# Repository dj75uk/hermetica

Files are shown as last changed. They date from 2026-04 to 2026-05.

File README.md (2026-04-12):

# Project Hermetica

## Overview
**Project Hermetica** is a modular, scalable **flight control unit (FCU) platform** designed for unmanned aerial systems ranging from hobby-grade builds to industrial and commercial UAVs.

It is built from the ground up to prioritise **reliability, observability, and architectural correctness**, avoiding the typical “black box” approach seen in many existing flight controllers.

## Purpose
Hermetica exists to solve a fundamental problem in UAV systems:

> Flight controllers are often opaque and difficult to validate, when they should be transparent, deterministic, and testable.

The platform aims to:
- Provide a **robust and distributed deterministic flight control stack**
- Enable **deep system introspection** for debugging and validation
- Support **modern communication architectures** (notably CAN-based systems)
- Serve as a foundation for **autonomous and safety-critical UAV applications**

## Design Philosophy
Hermetica is built on a set of strict engineering principles:

- **Modularity by design**  
  Components must be composable, replaceable, and independently testable  

- **Deterministic behaviour**  
  Timing, control loops, and data paths must be predictable and measurable  

- **Observability first**  
  Internal system state must be visible, logged, and analysable  

- **Fail explicitly, not silently**  
  Fault detection and handling are first-class concerns  

- **Architecture over convenience**  
  Clean design is prioritised over short-term integration hacks  

## System Architecture
Hermetica is structured as a **distributed flight control system**:

- **Power Management**
  
  Power supply, control, regulation, protection and monitoring.
  
- **Distibuted Core FCU**  
  High-performance MCU(s) responsible for control loops, sensor fusion, and coordination  

- **Peripheral Modules**  
  Sensors, actuators, and payload interfaces connected via defined interfaces  

- **Communication Backbone**  
  FDCAN-based architecture for robust, fault-tolerant communication  

- **Telemetry & Diagnostics Layer**  
  High-rate, structured data output for monitoring and analysis  

## Core Capabilities
- Multi-mode flight control (manual, stabilised, autonomous)  
- Sensor fusion (IMU, GNSS, barometer, magnetometer, optional optical flow)  
- High-frequency, deterministic control loops  
- Integrated health monitoring and fault detection  
- Comprehensive logging and telemetry streaming  
- Support for multiple protocols (CAN, UART, SBUS/FBUS, MAVLink)  

## Hardware Approach
Hermetica hardware is designed to be:
- **Electrically robust** (ESD protection, signal integrity, stable power delivery)  
- **Expandable** with clearly defined interfaces  
- **Integration-aware** without hardcoding external constraints  
- **Unconstrained by legacy layouts**  

## Software Approach
- Bare-metal or RTOS-based execution  
- Clear separation of:
  - Real-time control paths  
  - Communication layers  
  - Diagnostics and logging  
- Designed for **testability** (HIL/SIL, fault injection)  
- Secure update and configuration mechanisms  

## Relationship to Aetherion
Hermetica is developed alongside [**Project Aetherion**](https://github.com/dj75uk/aetherion), which serves as its **real-world validation platform**.

- Hermetica defines the control system  
- Aetherion validates it under real conditions  

This separation keeps Hermetica architecturally clean while ensuring it meets real-world constraints.

## Key Differentiators
- **CAN-first architecture** instead of UART-centric designs  
- **Proper FBUS support** for high-performance peripherals  
- **Deep observability and diagnostics**, not just basic telemetry  
- **Scalable design** from hobby to industrial applications  
- **Explicit fault handling**, not optimistic assumptions  

## Target Use Cases
- Advanced hobbyist UAV platforms  
- Research and academic systems  
- Industrial UAV development  
- Autonomous flight systems  

## Long-Term Vision
Hermetica is intended to evolve into:
- A fully autonomous flight control platform  
- A modular ecosystem with open interface specifications  
- A reference architecture for next-generation UAV systems  

Future directions include:
- Distributed flight control across multiple nodes  
- AI-assisted navigation and control  
- Swarm coordination  
- Pathways toward safety-critical certification

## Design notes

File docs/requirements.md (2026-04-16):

# Project Hermetica – System Requirements Specification

**Version:** 0.1  
**Date:** 2026-04-16  
**Owner:** Daniel Johnson  
**Status:** Draft  

---

## 1. Scope

This document defines the high-level system requirements for Project Hermetica.

These requirements describe what the system must achieve independent of specific implementation details.

---

## 2. Functional Requirements

### Flight Control

**FR-001 [MVP]**  
The system shall provide closed-loop stabilised flight control for fixed-wing UAV platforms.

**FR-002 [MVP]**  
The system shall support manual flight control input from at least one external RC receiver.

**FR-002 [MVP]**  
The system shall support aileron control surfaces.

**FR-002 [MVP]**  
The system shall support rudder control surfaces.

**FR-002 [MVP]**  
The system shall support elevator control surfaces.

**FR-002 [MVP]**  
The system shall support ruddervator control surfaces.

**FR-002 [FUTURE]**  
The system shall support elevon control surfaces.

**FR-002 [MVP]**  
The system shall support flap control surfaces.

**FR-002 [FUTURE]**  
The system shall support flapperon control surfaces.

**FR-002 [FUTURE]**  
The system shall support canard control surfaces.

**FR-003 [MVP]**
The system shall support at least 4 independant engines.

**FR-003 [MVP]**
The system shall support independant thrust curves for each engine.

**FR-004 [MVP]**
The system shall support multiple airframe configurations.

**FR-004 [MVP]**
The system shall support differential thrust.
- Source: DC-010, DC-025 

**FR-007 [MVP]**  
The system shall support multiple flight modes.

**FR-008 [FUTURE]**  
The system shall support autonomous mission execution.

**FR-009 [MVP]**  
The system shall generate independent control outputs for at least:
- throttle
- pitch
- roll
- yaw
- flaps

---

### Sensor Processing

**FR-012 [MVP]**  
The system shall acquire inertial measurement data from onboard sensors.

**FR-013 [MVP]**  
The system shall support fusion of:
- gyroscope
- accelerometer
- magnetometer

**FR-014 [FUTURE]**  
The system shall support optional integration of:
- GNSS
- barometric pressure
- pitot airspeed
- range sensors

---

### Distributed Architecture

**FR-015 [MVP]**  
The system shall support distributed processing across multiple nodes.

**FR-016 [MVP]**  
The system shall allow independent functional modules to be added without modification of the core flight controller.

**FR-017 [MVP]**  
The system shall support a minimum of 24 connected nodes.

---

## 3. Performance Requirements

**PR-001 [MVP]**  
The primary flight control loop shall operate at 1000 Hz with cycle-to-cycle jitter not exceeding 50 µs.

**PR-002 [MVP]**  
The system shall produce actuator command outputs at a minimum frequency of 500 Hz.

**PR-003 [MVP]**  
The system shall have and end-to-end control latency not exceeding 20 ms.

**PR-004 [MVP]**  
The system shall complete cold boot within 3 seconds.

**PR-005 [FUTURE]**  
The system shall scale to at least 24 networked nodes without loss of deterministic communication.

---

## 4. Safety Requirements

**SR-001 [MVP]**  
The system shall prevent actuator arming while debugging hardware is connected.

**SR-002 [MVP]**  
The system shall detect loss of critical sensor data.

**SR-003 [MVP]**  
The system shall detect loss of communication with critical nodes.

**SR-004 [MVP]**  
The system shall transition to a defined failsafe state upon loss of pilot control input.

**SR-005 [MVP]**  
The system shall reject commands that exceed defined airframe safety limits.

**SR-006 [MVP]**  
The system shall tolerate failure of non-critical nodes without loss of flight control.

---

## 5. Interface Requirements

### Internal Communication

**IR-001 [MVP]**  
The system shall support deterministic communication
between distributed nodes.

**IR-002 [MVP]**  
All stack layers shall communicate over a shared internal backbone.

**IR-003 [MVP]**  
The system shall support deterministic time-synchronised communication between nodes.

---

### External Interfaces

**IR-004 [MVP]**  
The system shall support at least one RC receiver interface.

**IR-005 [MVP]**  
The system shall provide a standardised debug interface on each stack layer.

**IR-006 [FUTURE]**  
The system shall support a ground telemetry interface.

---

## 6. Electrical Requirements

**ELR-001 [MVP]**  
The system shall operate from a dual redundant battery input.

**ELR-002 [MVP]**  
The system shall support an input voltage range of at least 2S to 8S LiPo equivalent.

**ELR-003 [MVP]**  
The system shall provide isolated power domains for:
- flight stack
- external nodes

**ELR-004 [MVP]**  
The system shall monitor:
- voltage
- current
- temperature
- power consumption

---

## 7. Mechanical Requirements

**MR-001 [MVP]**  
The system shall support a vertically stacked PCB architecture.

**MR-002 [MVP]**  
Individual stack layers shall be replaceable without redesign of adjacent layers.

**MR-003 [MVP]**  
External nodes shall connect using defined standard interfaces.

---

## 8. Environmental Requirements

**ENV-001 [MVP]**  
The system shall operate at temperatures between -20°C and +70°C minimum.

**ENV-002 [MVP]**  
The system shall tolerate vibration consistent with fixed-wing UAV operation.

**ENV-003 [FUTURE]**  
The system shall tolerate temporary electrical transients without system reset.

---

## 9. Maintainability Requirements

**MT-001 [MVP]**  
The system shall support firmware updates through a standardised service interface.

**MT-002 [MVP]**  
Each node shall support independent firmware programming.

**MT-003 [FUTURE]**  
The system shall support remote firmware updates.

---

## 10. Verification Requirements

**VR-001**  
Each requirement in this document shall be verifiable by one or more of:
- inspection
- analysis
- test
- demonstration

**VR-002**  
Each implemented subsystem shall trace back to one or more requirements defined in this document.

---

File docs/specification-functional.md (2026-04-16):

# Project Hermetica – System Specification

**Version:** 0.6  
**Date:** 2026-04-15  
**Owner:** Daniel Johnson  
**Status:** Draft  

---

## Nomenclature

### On the name "Hermetica"

### On the name "Aetherion"

### Definitions

#### FCU
The FCU is the Hermetica hardware and software combined together to form a working, cohesive system. It encompasses the centralised control system and any communicating devices.

#### Flight Control Stack
A centralised physical structure comprised of vertically stacked PCBs with a common Backbone, responsible for primary flight-critical functions.

#### Backbone
A vertically stacking header facilitating power distribution and signalling between Stack Layers.

#### Stack Layer
A physical PCB within the Flight Control Stack.

#### Node
A physical PCB external to the Flight Control Stack, connected via defined interfaces and operating semi-independently.

#### Role
A logical grouping of Responsibilities, independent of physical implementation.

#### Authority
The level of control a Role has over system behaviour and decision making.

#### Responsibility
A defined aspect of system behaviour that a Role is accountable for.

#### Power Domain
A distinct electrical rail with defined characteristics and purpose.

#### System State
The current operational state of the FCU and all information pertaining to it.

---

## Units

Wherever possible, SI units (and derived units) will be used across the system.

| Value | Unit | Symbol | Examples |
|---|---|---|---|
| Time | Seconds | s | |
| Attitute | degrees | ° | Roll, Pitch, Yaw |
| Attitute Rates | degrees per second | °s<sup>-1</sup> | Roll-Rate, Pitch-Rate, Yaw-Rate |
| Heading|degrees|°| Magnetic Heading, True Heading |
| Scalar speed |metres per second | ms<sup>-1</sup> | Airspeed, Groundspeed, VSI |
| Altitude | metres | m | Barometric altitude, GPS altitude, IMU altitude, Ranged altitude |
| Current | Amps  | A | Primary bus current |
| Voltage | Volts | V | Primary bus voltage |
| Power | Watts | W | Primary bus power |
|Frequency|Hertz|Hz| Main loop cycle frequency |
|Temperature|Celcius|°C| Outside air temperature, cabin temperature |
|Pressure|Pascals|Pa| Barometric pressure, Pitot pressure |
|Distance|metres|m| Total flight distance, distance to home |

---

## Purpose

Hermetica is a **modular, distributed, resiliant, scalable flight control unit (FCU) platform** designed to support UAV systems ranging from hobbyist to industrial-grade deployments.

The system is intended to:
- Provide **deterministic real-time flight control**
- Enable a **modular ecosystem**
- Establish a **CAN-FD-first architecture**
- Support progression toward **full autonomy**

---

## System Architecture

### Architectural Model

Hermetica follows a **hybrid architecture**:
- A **scalable, centralised Flight Control Stack** for flight-critical functions
- **Distributed Nodes** for extensibility and scalability

### Core Components

- Flight Control Stack
- External Nodes
- Sensor Systems
- Actuation Systems
- CAN-FD Backbone
- Ground Interface

### Design Principles

- **Strict role separation**
- **Decoupled integration** (no hard dependency on specific airframe)
- **Deterministic real-time behavior**
- **Fail-operational where possible**
- **Hardware/software modularity**
- **Open interface specifications**

---

## Logical System Model

### [CAN-FD Message Model](message-model.md)

### System State

The System State is effectively a normalised view of the current operating conditions of the FCU and the airframe.

| Variable | Data Type | Notes |
|---|---|---|
| Bench Mode | BOOL | |
| Launched | BOOL | |
| Armed | BOOL | |
| Current Flight Mode | ENUM | |
| Current Throttle Rate | FLOAT | |
| Current Pitch Rate | FLOAT | |
| Current Roll Rate | FLOAT | | 
| Current Yaw Rate | FLOAT | | 
| Current Throttle | FLOAT | |
| Current Pitch | FLOAT | |
| Current Roll | FLOAT | | 
| Current Yaw | FLOAT | | 
| Current Flaps | FLOAT | | 
| Current VSI | FLOAT | | 
| Current Barometric Pressure | FLOAT | | 
| Current Pitot Pressure | FLOAT | | 
| Current Barometric Altitude | FLOAT | | 
| Current GPS Altitude | FLOAT | | 
| Current Ranged Altitude | FLOAT | | 

| Variable | Data Type | Notes |
|---|---|---|
| Input Throttle | FLOAT | |
| Input Pitch | FLOAT | |
| Input Roll | FLOAT | | 
| Input Yaw | FLOAT | | 
| Input Flaps | FLOAT | | 
| Input Differential Throttle | FLOAT | Left/Right Throttle bias for twin-engines | 
| Input Flight Mode | ENUM | | 

| Variable | Data Type | Notes |
|---|---|---|
| Output Throttle | FLOAT | |
| Output Pitch | FLOAT | |
| Output Roll | FLOAT | | 
| Output Yaw | FLOAT | | 
| Output Flaps | FLOAT | | 
| Output Differential Throttle | FLOAT | | 

### Roles

A Role:
- Owns a clearly defined functional domain
- Has explicitly defined inputs and outputs
- May enforce local constraints within its domain
- May participate in system-wide decision making depending on its authority

The FCU is composed of a set of defined Roles. Each Role encapsulates a specific set of Responsibilities and operates within a defined domain.

Roles are independent of physical implementation and may be assigned to any suitable Stack Layer or Node.

---

#### Flight Control Role

The Flight Control Role is responsible for generating actuator commands required to achieve and maintain controlled flight.

Responsibilities:
- Stabilisation (rate and attitude control)
- Navigation (position and velocity control)
- Flight mode handling and transitions
- Command generation for actuators
- Enforcement of flight-related constraints

Inputs:
- Sensor data (IMU, GNSS, barometer, etc.)
- Pilot commands (via RC or ground interface)
- System State
- Constraints from higher-authority roles

Outputs:
- Actuator command signals
- Flight state information

---

#### Sensor Processing Role

The Sensor Processing Role is responsible for acquiring, validating, and conditioning sensor data for use by other Roles.

Responsibilities:
- Sensor data acquisition
- Calibration and compensation
- Data validation and plausibility checking
- Sensor fusion (if implemented within this role)

Inputs:
- Raw sensor measurements

Outputs:
- Conditioned sensor data
- State estimates (if applicable)
- Sensor health/status information

---

#### Actuation Role

The Actuation Role is responsible for converting actuator commands into physical outputs.

Responsibilities:
- Driving ESCs and servos
- Output signal generation (PWM, digital protocols, etc.)
- Monitoring actuator response (if feedback is available)
- Enforcing actuator-level safety constraints

Inputs:
- Actuator commands from Flight Control Role
- System State
- Constraints from higher-authority roles

Outputs:
- Physical actuator signals
- Actuator status and health information

---

#### Power Management Role

The Power Management Role is responsible for the distribution, monitoring, and protection of electrical power within the FCU.

Responsibilities:
- Power distribution across defined Power Domains
- Voltage, current, and temperature monitoring
- Fault detection and protection
- Power domain control (enable/disable)
- Enforcement of electrical safety constraints

Inputs:
- Electrical measurements (voltage, current, temperature)
- System State

Outputs:
- Power status information
- Fault signals
- Power domain control signals

---

#### Communication Role

The Communication Role is responsible for the exchange of data between system components and external interfaces.

Responsibilities:
- Message transport across internal and external interfaces
- Protocol handling and abstraction
- Routing of messages between Roles
- Ensuring data integrity and timing constraints

Inputs:
- Messages from Roles and external interfaces

Outputs:
- Routed and transmitted messages
- Communication status information

---

#### System Management Role

The System Management Role is responsible for overall system coordination and state management.

Responsibilities:
- System State management and transitions
- Arming and disarming logic
- Coordination between Roles
- Enforcement of system-level constraints
- Handling of global fault conditions

Inputs:
- Status and health information from all Roles
- External control inputs

Outputs:
- System State
- Control signals affecting other Roles
- Global fault responses

---

#### Payload Role

The Payload Role is responsible for control and management of mission-specific payloads.

Responsibilities:
- Payload control and operation
- Data acquisition from payload systems
- Integration with mission objectives

Inputs:
- Commands from Flight Control or external interfaces

Outputs:
- Payload data
- Payload status information

---

### Responsibilities

Responsibilities define behavioural obligations of Roles.

#### Assignment

- Every Responsibility shall be owned by exactly one Role.  
- A Role may own multiple Responsibilities.  
- Responsibilities shall not be shared between Roles to avoid ambiguity in ownership.  

---

#### Scope

- Each Responsibility shall have clearly defined boundaries.  
- Responsibilities shall not overlap in scope.  
- Responsibilities may depend on outputs from other Responsibilities but shall not duplicate them.  

---

#### Inputs and Outputs

- Each Responsibility shall define its required inputs.  
- Each Responsibility shall define its expected outputs.  
- Inputs and outputs shall be explicitly defined to enable consistent integration between Roles.  

---

#### Behavioural Guarantees

- Each Responsibility shall define the conditions it must maintain or enforce.  
- Responsibilities shall produce deterministic outcomes given valid inputs.  
- Responsibilities shall handle invalid or missing inputs in a defined manner.  

---

#### Constraints

- Responsibilities may enforce constraints within their domain.  
- Responsibilities shall operate within constraints imposed by higher-authority Roles.  
- Conflicting constraints shall be resolved according to the Authority model.  

---

#### Failure Handling

- Each Responsibility shall define failure conditions relevant to its domain.  
- Responsibilities shall detect and report failures where possible.  
- Responsibilities shall define safe behaviour in the presence of faults.  

---

#### Independence

- Responsibilities shall be independent of physical implementation.  
- Responsibilities shall not assume specific hardware, communication interfaces, or execution environments.  

---

#### Composability

- Responsibilities shall be designed to allow composition into larger system behaviours.  
- Responsibilities may be reused across different Roles or system configurations, provided ownership remains unambiguous.  

---

### Authority Model

- Higher-authority Roles define intent and constraints
- Lower-authority Roles execute within constraints
- Lower layers may reject unsafe commands
- System Management Role arbitrates conflicts
- Power Management Role has ultimate override in electrical faults

---

### Hierarchical Control Architecture

The FCU implements a hierarchical control architecture where high-level intent is progressively transformed into physical actuation.

---

#### Strategic Level (may be omitted)
- Defines long-term objectives (map this entire area)

#### Tactical Level
- Defines short-term objectives (waypoints, timing)

#### Execution Level
- Generates paths and vectors

#### Flight Dynamics Level
- Converts paths into attitude/altitude targets

#### Flight Control Level
- Stabilises via control loops

#### Actuation Level
- Drives physical outputs

---

## Functional Capabilities

### Flight Control

- Stabilisation
- Navigation
- Mission execution

(Control strategy TBD)

---

### Flight Modes

- **Disabled / Fully Manual Control**  
Direct RC receiver pass-through with no protection from pilot error

#### Building Blocks

- **Controlled Throttle**  
Throttle is directly proportional to pilot input within configurable safety margins
- **Controlled Pitch-Rate**  
Pitch-rate is directly proportional to pilot input within configurable safety margins
- **Controlled Pitch**  
Pitch is directly proportional to pilot input within configurable safety margins
- **Controlled Roll-Rate**  
Roll-rate is directly proportional to pilot input within configurable safety margins
- **Controlled Roll**  
Roll is directly proportional to pilot input within configurable safety margins
- **Controlled Yaw-Rate**  
Yaw-rate is directly proportional to pilot input within configurable safety margins

- **Auto Pitch-Rate**  
Pitch is controlled by the FCU, any pilot input disables **Auto Pitch-Rate** and enables **Controlled Pitch-Rate**

- **Auto Pitch**  
Pitch is controlled by the FCU, any pilot input disables **Auto Pitch** and enables **Controlled Pitch**

- **Auto Roll-Rate**  
Pitch is controlled by the FCU, any pilot input disables **Auto Roll-Rate** and enables **Controlled Roll-Rate**

- **Auto Roll**  
Pitch is controlled by the FCU, any pilot input disables **Auto Roll** and enables **Controlled Roll**

- **Altitude Hold**

- **Airspeed Hold**
  - Enables **Controlled Throttle**

#### Basic Flight Modes

- **Semi-Manual**  
Limited RC receiver pass-through with configurable airframe and flight-envelope protection
- **Stabilised**  
IMU assisted flight, airframe will maintain whatever *attitude-rates* the pilot commands
  - Enables **Controlled Throttle**
  - Enables **Controlled Pitch-Rate**
  - Enables **Controlled Roll-Rate**
  - Enables **Controlled Yaw-Rate**
- **Autolevel**  
IMU assisted flight, airframe will maintain whatever *attitude* the pilot commands until the command is ceased, then the airframe will self-level pitch and roll
  - Pilot throttle input controls throttle directly
  - Pilot yaw input controls rudder directly
  - Pilot pitch input controls final pitch angle
  - Pilot roll input controls final roll angle

- **Launch** *TODO: This seems unsafe, review*    
Aircraft will maintain a preset throttle and pitch angle until the mode is disengaged
  - Pilot throttle input controls are disabled, the aircraft maintains the configured launch throttle
  - Pilot yaw input controls are disabled, the aircraft maintains the yaw angle of launch
  - Pilot pitch input controls are disabled, the aircraft maintains the configured launch pitch
  - Pilot roll input controls are disabled, the aircraft maintains a roll angle of zero  

- **Loiter**  
Aircraft will fly in a circle around the location the aircraft is at when the mode is enabled, maintaining a fixed altitude. If no GPS/GNSS is available then the aircraft will use the IMU to maintain a constant yaw rate while maintaining a fixed altitude.

#### Advanced Flight Modes

- **Return To Home (RTH)**  
Aircraft will return to the point the flight started then enter **Loiter** mode at that point

- **Failsafe**
- **Autonomous**

---

| Mode | Throttle  |  Yaw | Pitch | Roll | Flaps |
|---|---|---|---|---|---|
| Full-Manual | Direct | Direct | Direct | Direct | Direct |
| Semi-Manual | Limited | Limited | Limited | Limited | Limited |
| Stabilised  |-----------|------|-------|------|-------|
| Autolevel |-----------|------|-------|------|-------|
| Loiter |-----------|------|-------|------|-------|
| RTH |-----------|------|-------|------|-------|
| Launch |-----------|------|-------|------|-------|
| Full-manual |-----------|------|-------|------|-------|
| Full-manual |-----------|------|-------|------|-------|
| Full-manual |-----------|------|-------|------|-------|
| Full-manual |-----------|------|-------|------|-------|
| Full-manual |-----------|------|-------|------|-------|
| Full-manual |-----------|------|-------|------|-------|
| Full-manual |-----------|------|-------|------|-------|
| Full-manual |-----------|------|-------|------|-------|
| Full-manual |-----------|------|-------|------|-------|
| Full-manual |-----------|------|-------|------|-------|

---

### Sensor Handling

- IMU, GNSS, Barometer, Magnetometer
- Optional sensors

Sensor fusion TBD

---

### Communication

#### Flight Stack Backbone:

The Backbone must provide both power, data about the power and communications and signalling. 

**Power:**

| Name | Notes |
|---|---|
| 5V<sub>STACK</sub> | Power bus for the Flight Stack |
| 5V<sub>NODES</sub> | Power bus for the Nodes | 
| GND<sub>POWER</sub> | Power ground |
| GND<sub>SIGNAL</sub>  | Signal ground |

**Communications & Signalling:**

| Name | Data type | Description |
|---|---|---|
| PG<sub>STACK</sub> | BOOL | 5V<sub>STACK</sub> power good |
| LOAD<sub>STACK</sub>  | SCALAR | Load of 5V<sub>STACK</sub> bus |
| PG<sub>NODES</sub> | BOOL | 5V<sub>NODES</sub> power good |
| LOAD<sub>NODES</sub>  | SCALAR | Load of 5V<sub>NODES</sub> bus |
| CAN1 | DIFF | CAN-FD communications bus |
| CAN2 | DIFF | CAN-FD communications bus |
| RESET | BOOL | Flight Stack reset signal |
| ARMED | BOOL | FCU "Armed" state |
| SYNC | BOOL | Deterministic synchronisation pulse |
| BENCH | BOOL | Debugger plugged in somewhere |

**Secondary Interfaces:**
- UART (FBUS, SBUS, GPS, debugging)
- SPI / I²C (local peripherals)

---

### Payload Control

- CAN-FD controlled payloads

---

### Logging & Telemetry

- Storage
- Streaming
- Blackbox

---

## Physical System

### Standardised Parts List

Although individual nodes will require specific hardware, it is sensible to standard parts across all components where feasible.

| Type | Manufacturer | Part Number | Package |
|---|---|---|---|
| Microcontroller  | STM | STM32H755ZIT6 | LQFP-144 20x20x1.4 |
| Microcontroller  | STM | STM32G484CET6 | LQFP-48 7x7x1.4 |
| |  |  |  |
| |  |  |  |
| |  |  |  |
| |  |  |  |

---

### Physical Architecture

- Vertical PCB stack
- External nodes
- Backbone interconnect

---

### Processing Architecture

- MCU: Will be dependant upon individual stack layer requirements:
  - STM32H755ZIT6 for high performance layers running at 480 MHz  
  - STM32G484CET6 for low performance requirements running at 170 MHz  

| MCU | Core | Clock Speed | Package |
|---|---|---|---|
| STM32H755ZIT6 | M7 + M4 (Dual Core) | 480 Mhz | LQFP-144 20x20x1.4 |
| STM32G484CET6 | M4 | 170 Mhz | LQFP-48 7x7x1.4 |

---

### Memory

| MCU | Flash | RAM | 
|---|---|---|
| STM32H755ZIT6 | 2048 kB | 1024 kB |
| STM32G484CET6 | 512 kB  | 128 kB  |

- External storage: Each MCU will have dedicated FRAM for local configuration.  

---

### Electrical Architecture

- Dual 2S–8S input with automatic failover
- Multiple power domains
- Protection systems

---

#### System Power

##### Power Domain PD1

Source: Primary Batteries (2S to 8S), Dual configuration with automatic failover  
Voltage: 6.0V to 33.6V  
Current: 8A max  
Usage: Source for PD2, PD3, PD4  

---

##### Power Domain PD2

Source: PD1  
Voltage: 6.0V to 33.6V  
Current: 2A max  
Usage: Primary power pass-through for VTX etc  

---

##### Power Domain PD3

Source: PD1  
Voltage: 5V  
Current: 3A max  
Usage: Primary 5V for Flight Stack  

---

##### Power Domain PD4

Source: PD1  
Voltage: 5V  
Current: 3A max  
Usage: Primary 5V for Nodes  

---

### Hardware Platform

- STM32H755ZIT6
- STM32G484CET6
- FRAM per node

---

### Interfaces

- FDCAN (dual)
- UART
- SPI
- I²C
- GPIO

---

### Backbone

| | Name | Notes |
|---|---|---|
| | CAN1<sub>LOW</sub>, CAN1<sub>HIGH</sub>, GND<sub>SIGNAL</sub> | Primary CAN-FD communications bus |
| | CAN2<sub>LOW</sub>, CAN2<sub>HIGH</sub>, GND<sub>SIGNAL</sub> | Secondary CAN-FD communications bus |
| | 5V<sub>STACK</sub>, GND<sub>POWER</sub> | 5V/3A power bus for powering the Flight Stack |
| | 5V<sub>NODES</sub>, GND<sub>POWER</sub> | 5V/3A power bus for powering the Nodes |
| | nRESET | Active low, Flight Stack reset signal |
| | ARMED | Active high, FCU "Armed" state |
| | PGOOD<sub>STACK</sub> | Active high, 5V<sub>STACK</sub> power good |
| | PGOOD<sub>NODES</sub> | Active high, 5V<sub>NODES</sub> power good |
| | nFAULT | Active low, Flight Stack catastrophic fault signal |
| | LOAD<sub>STACK</sub> | Load of 5V<sub>STACK</sub> bus |
| | LOAD<sub>NODES</sub> | Load of 5V<sub>NODES</sub> bus |
| | SYNC | Active high, periodic deterministic pulse for synchronisation |

| Name | Notes |
|---|---|
| 5V<sub>STACK</sub> | Power bus for the Flight Stack |
| 5V<sub>NODES</sub> | Power bus for the Nodes | 
| GND<sub>POWER</sub> | Power ground |
| GND<sub>SIGNAL</sub>  | Signal ground |

**Communications & Signalling:**

| Name | Data type | Description |
|---|---|---|
| PG<sub>STACK</sub> | BOOL | 5V<sub>STACK</sub> power good |
| LOAD<sub>STACK</sub>  | SCALAR | Load of 5V<sub>STACK</sub> bus |
| PG<sub>NODES</sub> | BOOL | 5V<sub>NODES</sub> power good |
| LOAD<sub>NODES</sub>  | SCALAR | Load of 5V<sub>NODES</sub> bus |
| CAN1 | DIFF | CAN-FD communications bus |
| CAN2 | DIFF | CAN-FD communications bus |
| RESET | BOOL | Flight Stack reset signal |
| ARMED | BOOL | FCU "Armed" state |
| SYNC | BOOL | Deterministic synchronisation pulse |
| BENCH | BOOL | Debugger plugged in somewhere |

##### CAN1<sub>LOW</sub>, CAN1<sub>HIGH</sub>

##### CAN2<sub>LOW</sub>, CAN2<sub>HIGH</sub>

##### 5V<sub>STACK</sub>, GND<sub>POWER</sub>

##### 5V<sub>NODES</sub>, GND<sub>NODES</sub>

##### nRESET

(Hard to seperate logical from physical here.)

The nRESET signal may be set LOW by any Stack Layer in the Flight Control Stack.
The signal is pulled HIGH by default by the Stack Layer with the Power Management Role.

---

### Flight Stack Layers

All Flight Stack Layers communicate over the Backbone via CAN1, CAN2, or both.

#### Power Distribution Board

The PDB is the central electrical hub of a system designed to take power from the main battery and distribute it safely and efficiently to all subsystems.

- STM32G484CET6
- I/O: Debug connector
- IN: Connection for primary batteries (PD1)
- OUT: (PD1) 2x low current (2A) pass-through VTX connections
- OUT: (PD2) Voltage regulation to 5.0V @ 3A for stack power  
- OUT: (PD3) Voltage regulation to 5.0V @ 3A for distributed node power (PD3)
- Current, voltage, temperature, coulomb counting and power monitoring
- Feeds power good signals on backbone (PD2 and PD3)
- Feeds power load signals on backbone (PD2 and PD3)
- ESD protection, reverse voltage protection, reverse current blocking, fusing
- MCU locally powered by local 3.3V regulation from PD2
- Optional CAN-FD bus termination
- Pulls backbone nRESET high to 3.3V via pull-up
- Cuts power temporarily to PD2 and PD3 on backbone nRESET signal going low

#### Flight Control Board

- STM32H755ZIT6
- I/O: Debug connector
- I/O: CAN-FD external connector
- Reads RC control messages from the CAN-FD bus from RC receivers
- Runs primary control loop, PID controllers, cascaded PID controllers services actuators
- MCU locally powered by local 3.3V regulation from PD2 via backbone  
- Functional IMU (gyroscope, accelerometer, magnetometer, barometer)  
- Primary consumer of CAN-FD messages from subsystems  
- Optional CAN-FD bus termination
- Responsible for feeding arming signal on backbone

  Roles:

#### Future Boards
- Navigation
- OSD
- Storage
- Radar

---

### Connectors

#### Debug Connector

Standardised connector across all PCB's for connection to a debugging board.

- Connector: Samtec T1M, 10 pin, horizontal, single-row, [SAMTEC-T1M-10-F-SH-L](https://www.samtec.com/products/t1m-10-f-sh-l)
- Height: 4.6mm

| Pin  | Name | Notes |
|---|---|---|
| 1 | V<sub>TARGET</sub> | Voltage of target MCU |
| 2 | GND | Target GND |
| 3 | nDebuggerPresent | Signal to indicate the debugging board is fitted to any Node or Flight Stack Layer (0V to V<sub>TARGET</sub>) |
| 4 | SWDIO | SWD - SWDIO signal |
| 5 | SWCLK | SWD - SWCLK signal |
| 6 | SWO | SWD - SWO signal |
| 7 | BOOT0 | Pull-down on target on board |
| 8 | nRESET | Pull-up on target board |
| 9 | MCU<sub>TX</sub> | UART connection to MCU TX |
| 10 | MCU<sub>RX</sub> | UART connection to MCU RX |

#### FITTED

FITTED is pulled to  V<sub>TARGET</sub> on the debugging board. This is to enable the detection of the debugging hardware should conditional logic be required.
For example, the FCU could refuse to arm the motors and spin the propellors if FITTED was high. You know, to save fingers.

#### BOOT0

BOOT0 is broken out so that the MCU can be forced to start in bootloader mode in an emergency. It should be pulled-down on the target PCB.

#### MCU<sub>TX</sub> and MCU<sub>RX</sub>
- 
MCU<sub>TX</sub> and MCU<sub>RX</sub> are broken out so that the MCU can be emergency flashed. They should be connected to a USART capable of flashing the bootloader.  
- For most STM32 MCU's this is USART1, USART2 or USART3. During normal operation, the USART may be used for debugging.  

---

#### CAN-FD Connector
Standardised connector across all PCB's for connection to a CAN-FD nodes.

- Connector: Samtec T1M, 3 pin, horizontal, single-row, [SAMTEC-T1M-03-F-SH-L](https://www.samtec.com/products/t1m-03-f-sh-l)
- Height: 4.6mm

| Pin  | Name | Notes |
|---|---|---|
| 1 | CAN<sub>LOW</sub>  | CAN Low |
| 2 | CAN<sub>HIGH</sub> | CAN High |
| 3 | GND | Signal ground |

### 4.9.1 CAN<sub>LOW</sub> and CAN<sub>HIGH</sub>

CAN<sub>LOW</sub> and CAN<sub>HIGH</sub> are a differential signal and should be twisted-pair.

---

## Firmware Architecture

### Execution Model
- The primary firmware will be written in C/C++ on a *baremetal* level (HAL is acceptable)  

---

## Safety & Fault Handling

### Fault Classes

- Sensor failure  
- Actuator failure  
- Power instability  
- Communication loss  
- Internal software fault  

---

### Detection Mechanisms

- [x] Watchdogs (independent + windowed)  
- [x] Heartbeats (inter-module)  
- [x] Plausibility checks  

---

### Failsafe Behaviour

|TBC

---

## Performance Targets

- Control loop frequency: 1 kHz  
- End-to-end latency: sub 20 ms  
- Boot time: sub 3 s  
- Minimum supported nodes (CANFD): 24  
- Minimum actuator count: 8  

---

## Environmental Requirements

- Operating temperature: -40C to 120C (low temperature handling is much more important)  
- TBC

---

## Security

TBC 

---

## Verification Strategy

TBC

---

## Integration Model

Hermetica must remain **independent of Aetherion** until integration.

### Negotiated Parameters

| Parameter | Hermetica Target | Aetherion Constraint | Status |
|---|---|---|---|
| Weight | < 500g | 1.0kg limit | [x] |
| Power | 2S to 8S supply, 500mA total consumption | ___ | [ ] |
| Size | 60mm(W) x 80mm(L) x 50mm(H) | ___ | [ ] |

---

## MVP Definition

**MVP must include:**
- CAN-FD working backbone for messaging between Flight Stack Layers and Nodes
- Basic stabilized flight  
- Basic loiter flight mode  
- Gyroscope, accelerometer and magnetometer fusion  
- RC input (SBUS)  
- PWM output for ESC and servos
- Independant control of ailerons, elevators, rudders and flaps  
- Basic failsafe  

**Explicitly excluded:**
- Advanced flight modes  
- Pitot integration  
- Payload ecosystem  
- OSD integration

---

## Future Extensions

TBC

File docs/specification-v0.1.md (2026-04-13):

# Project Hermetica – System Specification (Draft)

**Version:** 0.3  
**Date:** 2026-04-13  
**Owner:** Daniel Johnson  
**Status:** Draft / In Definition  

---

## 0. Nomenclature

### 0.1 On the name "Hermetica"

### 0.2 On the name "Aetherion"

### 0.3 Definitions

#### 0.3.1 FCU

The FCU is the Hermetica hardware and software combined together to form a working, cohesive unit. It emcompasses the centralised control system and any communicating devices.

#### 0.3.2 Flight Control Stack

The Flight Control Stack is a centralised physical point, comprised of multiple vertically stacked PCB's with a common Backbone header. Is is responsible for actually flying the airframe.                                                  

#### 0.3.3 Backbone

A vertically stacking header on each PCB in the Flight Control Stack to facilitate power distribution to Stack Layers and signalling between them.

#### 0.3.4 Stack Layer

A physical PCB within the vertical Flight Control Stack.

#### 0.3.5 Node

A physical PCB within the FCU, connected to, but external to the Flight Control Stack via defined interfaces and operating semi-independantly.

#### 0.3.6 Role

A Role defines a logical set of Responsibilites within the system, independent of physical implementation.

#### 0.3.7 Authority

Authority defines the level of control a role has over system behaviour.

#### 0.3.8 Power Domain

A Power Domain is a distinct electrical rail with defined voltage, current capability, and purpose.

#### 0.3.9 System State

The System State represents the current operational mode of the FCU.

#### 0.3.10 Responsibility

A Responsibility is a defined aspect of system behaviour that a Role is accountable for, independent of implementation.

---

## 1. Purpose

Hermetica is a **modular, distributed, resiliant, scalable flight control unit (FCU) platform** designed to support UAV systems ranging from hobbyist to industrial-grade deployments.

The system is intended to:
- Provide **reliable real-time flight control**
- Enable a **modular hardware + software ecosystem**
- Establish **CAN-FD-first architecture** for UAV systems
- Support progression toward **fully autonomous operation**

---

## 2. System Definition

### 2.1 High-Level Architecture

**Core Components:**
- Flight Control Unit (FCU)
- Sensor Suite (external + onboard)
- Actuation Interfaces (ESCs, servos)
- Communication Backbone (CANFD-centric)
- Ground Interface

**Architecture Model:**
- A central flight control "stack" with multiple external nodes.
- The system will be inheirantly distributed with components performing strict roles with strict responsibilities.
- 
---

### 2.2 Design Principles

- **Decoupled integration** (no hard dependency on specific airframe)
- **Deterministic real-time behavior**
- **Fail-operational where possible**
- **Hardware/software modularity**
- **Open interface specifications**

---

## 3. Functional Scope

### 3.0 Roles, Authority and Responsibilites

A Role:
- Owns a clearly defined functional domain
- Has explicitly defined inputs and outputs
- May enforce local constraints within its domain
- May participate in system-wide decision making depending on its authority

The FCU is composed of a set of defined Roles. Each Role encapsulates a specific set of Responsibilities and operates within a defined domain.

Roles are independent of physical implementation and may be assigned to any suitable Stack Layer or Node.

---

#### 3.0.5 Flight Control Role

The Flight Control Role is responsible for generating actuator commands required to achieve and maintain controlled flight.

Responsibilities:
- Stabilisation (rate and attitude control)
- Navigation (position and velocity control)
- Flight mode handling and transitions
- Command generation for actuators
- Enforcement of flight-related constraints

Inputs:
- Sensor data (IMU, GNSS, barometer, etc.)
- Pilot commands (via RC or ground interface)
- System State
- Constraints from higher-authority roles

Outputs:
- Actuator command signals
- Flight state information

---

#### 3.0.10 Sensor Processing Role

The Sensor Processing Role is responsible for acquiring, validating, and conditioning sensor data for use by other Roles.

Responsibilities:
- Sensor data acquisition
- Calibration and compensation
- Data validation and plausibility checking
- Sensor fusion (if implemented within this role)

Inputs:
- Raw sensor measurements

Outputs:
- Conditioned sensor data
- State estimates (if applicable)
- Sensor health/status information

---

#### 3.0.15 Actuation Role

The Actuation Role is responsible for converting actuator commands into physical outputs.

Responsibilities:
- Driving ESCs and servos
- Output signal generation (PWM, digital protocols, etc.)
- Monitoring actuator response (if feedback is available)
- Enforcing actuator-level safety constraints

Inputs:
- Actuator commands from Flight Control Role
- System State
- Constraints from higher-authority roles

Outputs:
- Physical actuator signals
- Actuator status and health information

---

#### 3.0.20 Power Management Role

The Power Management Role is responsible for the distribution, monitoring, and protection of electrical power within the FCU.

Responsibilities:
- Power distribution across defined Power Domains
- Voltage, current, and temperature monitoring
- Fault detection and protection
- Power domain control (enable/disable)
- Enforcement of electrical safety constraints

Inputs:
- Electrical measurements (voltage, current, temperature)
- System State

Outputs:
- Power status information
- Fault signals
- Power domain control signals

---

#### 3.0.25 Communication Role

The Communication Role is responsible for the exchange of data between system components and external interfaces.

Responsibilities:
- Message transport across internal and external interfaces
- Protocol handling and abstraction
- Routing of messages between Roles
- Ensuring data integrity and timing constraints

Inputs:
- Messages from Roles and external interfaces

Outputs:
- Routed and transmitted messages
- Communication status information

---

#### 3.0.30 System Management Role

The System Management Role is responsible for overall system coordination and state management.

Responsibilities:
- System State management and transitions
- Arming and disarming logic
- Coordination between Roles
- Enforcement of system-level constraints
- Handling of global fault conditions

Inputs:
- Status and health information from all Roles
- External control inputs

Outputs:
- System State
- Control signals affecting other Roles
- Global fault responses

---

#### 3.0.35 Payload Role (Optional)

The Payload Role is responsible for control and management of mission-specific payloads.

Responsibilities:
- Payload control and operation
- Data acquisition from payload systems
- Integration with mission objectives

Inputs:
- Commands from Flight Control or external interfaces

Outputs:
- Payload data
- Payload status information

---

### 15.10 Responsibilities

Responsibilities define the behavioural obligations of Roles within the FCU.

Each Responsibility represents a specific aspect of system behaviour that must be fulfilled for correct operation.

---

#### 15.10.5 Assignment

- Every Responsibility shall be owned by exactly one Role.  
- A Role may own multiple Responsibilities.  
- Responsibilities shall not be shared between Roles to avoid ambiguity in ownership.  

---

#### 15.10.10 Scope

- Each Responsibility shall have clearly defined boundaries.  
- Responsibilities shall not overlap in scope.  
- Responsibilities may depend on outputs from other Responsibilities but shall not duplicate them.  

---

#### 15.10.15 Inputs and Outputs

- Each Responsibility shall define its required inputs.  
- Each Responsibility shall define its expected outputs.  
- Inputs and outputs shall be explicitly defined to enable consistent integration between Roles.  

---

#### 15.10.20 Behavioural Guarantees

- Each Responsibility shall define the conditions it must maintain or enforce.  
- Responsibilities shall produce deterministic outcomes given valid inputs.  
- Responsibilities shall handle invalid or missing inputs in a defined manner.  

---

#### 15.10.25 Constraints

- Responsibilities may enforce constraints within their domain.  
- Responsibilities shall operate within constraints imposed by higher-authority Roles.  
- Conflicting constraints shall be resolved according to the Authority model.  

---

#### 15.10.30 Failure Handling

- Each Responsibility shall define failure conditions relevant to its domain.  
- Responsibilities shall detect and report failures where possible.  
- Responsibilities shall define safe behaviour in the presence of faults.  

---

#### 15.10.35 Independence

- Responsibilities shall be independent of physical implementation.  
- Responsibilities shall not assume specific hardware, communication interfaces, or execution environments.  

---

#### 15.10.40 Composability

- Responsibilities shall be designed to allow composition into larger system behaviours.  
- Responsibilities may be reused across different Roles or system configurations, provided ownership remains unambiguous.  

---

### 3.1 Control Stack

- Stabilization (rate + attitude)
- Navigation (position, velocity)
- Mission execution (waypoints, behaviours)

**Control Strategy:**
- [ ] PID  
- [ ] Cascaded PID  
- [ ] MPC  
- [ ] Adaptive / ML-assisted  

> **Selected Strategy:** ___________

---

### 3.2 Flight Modes

- [ ] Manual passthrough  
- [ ] Stabilized  
- [ ] Assisted (altitude / position hold)  
- [ ] Fully autonomous  
- [ ] Return-to-home (RTH)
- [ ] Loiter
- [ ] Failsafe modes  

---

### 3.3 Sensor Handling

**Supported Sensors:**
- IMU (primary + redundant)
- GNSS
- Barometer
- Magnetometer
- [ ] Optical flow  
- [ ] Airspeed sensor  
- [ ] Radar / LiDAR  

**Sensor Fusion:**
- [ ] EKF  
- [ ] UKF  
- [ ] Custom  

> **Selected Approach:** ___________

---

### 3.4 Communication

**Primary Backbone:**
- FDCAN (mandatory)

**Secondary Interfaces:**
- UART (FBUS, SBUS, GPS, debugging)
- SPI / I²C (local peripherals)

**Protocol Stack:**
- [ ] MAVLink  
- [ ] Custom CAN protocol  
- [ ] DDS / ROS2 bridge  

> **Telemetry Rate Target:** ___________  
> **Max Latency:** ___________

---

### 3.5 Payload Control

- Controlled via CAN-FD messaging
  
---

### 3.6 Logging & Telemetry

- [ ] Onboard storage (SD / flash)  
- [ ] Real-time telemetry streaming  
- [ ] Blackbox flight recorder  

**Retention Target:** ___________

---

## 4. Physical - Hardware Specification

### 4.0 Standardised Parts List

Although individual nodes will require specific hardware, it is sensible to standard parts across all components where feasible.

| Type | Manufacturer | Part Number | Package |
|---|---|---|---|
| Microcontroller  | STM | STM32H755ZIT6 | LQFP-144 20x20x1.4 |
| Microcontroller  | STM | STM32G484CET6 | LQFP-48 7x7x1.4 |
| |  |  |  |
| |  |  |  |
| |  |  |  |
| |  |  |  |

### 4.1 Processing Architecture

- MCU: Will be dependant upon individual stack layer requirements:
  - STM32H755ZIT6 for high performance layers running at 480 MHz  
  - STM32G484CET6 for low performance requirements running at 170 MHz  

| MCU | Core | Clock Speed | Package |
|---|---|---|---|
| STM32H755ZIT6 | M7 + M4 (Dual Core) | 480 Mhz | LQFP-144 20x20x1.4 |
| STM32G484CET6 | M4 | 170 Mhz | LQFP-48 7x7x1.4 |

### 4.2 Memory

| MCU | Flash | RAM | 
|---|---|---|
| STM32H755ZIT6 | 2048 kB | 1024 kB |
| STM32G484CET6 | 512 kB  | 128 kB  |

- External storage: Each MCU will have dedicated FRAM for local configuration.  

---

### 4.3 Common interface usage

| Interface | Usage |
|---|---|
| FDCAN | Redundant primary backbone |
| UART | Debugging connector, low speed communication |
| SPI | Local FRAM, high-speed sensors |
| I²C | Low-speed sensors |
| GPIO | General low-speed signalling and input capture |
| PWM | Avoid using unless explicitly required on node |
| ADC | Avoid using if possible, prefer digital interfaces |
| DAC | Avoid using if possible, prefer digital interfaces |

---

#### 4.3.1 Standard peripheral usage by MCU

| MCU | FDCAN1 | FDCAN2 | SPI1 | USART3 |
|---|---|---|---|---|
| STM32H755ZIT6 | Primary Backbone | Primary Backbone | FRAM | Debugging |
| STM32G484CET6 | Primary Backbone | Primary Backbone | FRAM | Debugging |

- This should be considered a "standard usage" across all boards.
  
---

### 4.4 Power

- Input voltage range: 2S to 8S primary supply (6.0V to 33.6V)  
- Nominal power draw: < 500mA  
- Peak power draw: 3A  

- [x] Reverse polarity protection  
- [x] Surge / transient protection  
- [x] Power domain isolation  

---

### 4.5 Physical

- Form factor: Multiple-PCB vertical stack with a stacking header acting as a common backbone  
- Dimensions: 60mm(W) x 80mm(L) x  <50mm(H)  
- Weight target: Sub 500g including all control-cabling and nodes (excluding servos, batteries and ESC's)  
- Mounting via 4 x M3 holes, ideally on vibration mounts (airframe dependant)  

### 4.6 Backbone Header

The Backbone is the core communications layer of the Flight Control Stack. It contains a mixture of power and data.

The physical component for the Backbone Header has not yet been selected and is likely to change during early development stages.

#### 4.6.1 Logical Backbone Header

Without locking down a pinout, it is possible to define what power and data is required on the Backbone.

| | Name | Notes |
|---|---|---|
| | CAN1<sub>LOW</sub>, CAN1<sub>HIGH</sub>, GND<sub>SIGNAL</sub> | Primary CAN-FD communications bus |
| | CAN2<sub>LOW</sub>, CAN2<sub>HIGH</sub>, GND<sub>SIGNAL</sub> | Secondary CAN-FD communications bus |
| | 5V<sub>STACK</sub>, GND<sub>POWER</sub> | 5V/3A power bus for powering the Flight Stack |
| | 5V<sub>NODES</sub>, GND<sub>POWER</sub> | 5V/3A power bus for powering the Nodes |
| | nRESET | Active low, Flight Stack reset signal |
| | ARMED | Active high, FCU "Armed" state |
| | PGOOD<sub>STACK</sub> | Active high, 5V<sub>STACK</sub> power good |
| | PGOOD<sub>NODES</sub> | Active high, 5V<sub>NODES</sub> power good |
| | nFAULT | Active low, Flight Stack catastrophic fault signal |
| | LOAD<sub>STACK</sub> | Load of 5V<sub>STACK</sub> bus |
| | LOAD<sub>NODES</sub> | Load of 5V<sub>NODES</sub> bus |
| | SYNC | Active high, periodic deterministic pulse for synchronisation |

##### 4.6.1 CAN1<sub>LOW</sub>, CAN1<sub>HIGH</sub>

##### 4.6.2 CAN2<sub>LOW</sub>, CAN2<sub>HIGH</sub>

##### 4.6.3 5V<sub>STACK</sub>, GND<sub>POWER</sub>

##### 4.6.4 5V<sub>NODES</sub>, GND<sub>NODES</sub>

##### 4.6.5 nRESET

(Hard to seperate logical from physical here.)

The nRESET signal may be set LOW by any Stack Layer in the Flight Control Stack.
The signal is pulled HIGH by default by the Stack Layer with the Power Management Role.

### 4.7 

### 4.7 Flight Stack Layers

All Flight Stack Layers communicate over the Backbone via CAN1, CAN2, or both.

#### 4.7.1 Power Distribution Board (PDB)

The PDB is the central electrical hub of a system designed to take power from the main battery and distribute it safely and efficiently to all subsystems.

- STM32G484CET6
- I/O: Debug connector
- IN: Connection for primary batteries (PD1)
- OUT: (PD1) 2x low current (2A) pass-through VTX connections
- OUT: (PD2) Voltage regulation to 5.0V @ 3A for stack power  
- OUT: (PD3) Voltage regulation to 5.0V @ 3A for distributed node power (PD3)
- Current, voltage, temperature, coulomb counting and power monitoring
- Feeds power good signals on backbone (PD2 and PD3)
- Feeds power load signals on backbone (PD2 and PD3)
- ESD protection, reverse voltage protection, reverse current blocking, fusing
- MCU locally powered by local 3.3V regulation from PD2
- Optional CAN-FD bus termination
- Pulls backbone nRESET high to 3.3V via pull-up
- Cuts power temporarily to PD2 and PD3 on backbone nRESET signal going low

#### 4.7.1 Flight Control Board (FCB)

- STM32H755ZIT6
- I/O: Debug connector
- I/O: CAN-FD external connector
- Reads RC control messages from the CAN-FD bus from RC receivers
- Runs primary control loop, PID controllers, cascaded PID controllers services actuators
- MCU locally powered by local 3.3V regulation from PD2 via backbone  
- Functional IMU (gyroscope, accelerometer, magnetometer, barometer)  
- Primary consumer of CAN-FD messages from subsystems  
- Optional CAN-FD bus termination
- Responsible for feeding arming signal on backbone

  Roles:

#### 4.7.2 Advanced Navigation & Mission Board

- TBC

#### 4.7.2 OSD and video integration

- TBC

#### 4.7.2 Blackbox and Telemetry Storage

- TBC

#### 4.7.2 RADAR Data Processing Board

- TBC

---

### 4.8 Debug Connector

Standardised connector across all PCB's for connection to a debugging board.

- Connector: Samtec T1M, 10 pin, horizontal, single-row, [SAMTEC-T1M-10-F-SH-L](https://www.samtec.com/products/t1m-10-f-sh-l)
- Height: 4.6mm

| Pin  | Name | Notes |
|---|---|---|
| 1 | V<sub>TARGET</sub> | Voltage of target MCU |
| 2 | GND | Target GND |
| 3 | FITTED | Signal to indicate the debugging board is fitted to a target board (0V to V<sub>TARGET</sub>) |
| 4 | SWDIO | SWD - SWDIO signal |
| 5 | SWCLK | SWD - SWCLK signal |
| 6 | SWO | SWD - SWO signal |
| 7 | BOOT0 | Pull-down on target on board |
| 8 | nRESET | Pull-up on target board |
| 9 | MCU<sub>TX</sub> | UART connection to MCU TX |
| 10 | MCU<sub>RX</sub> | UART connection to MCU RX |

#### 4.8.1 FITTED

FITTED is pulled to  V<sub>TARGET</sub> on the debugging board. This is to enable the detection of the debugging hardware should conditional logic be required.
For example, the FCU could refuse to arm the motors and spin the propellors if FITTED was high. You know, to save fingers.

#### 4.8.2 BOOT0

BOOT0 is broken out so that the MCU can be forced to start in bootloader mode in an emergency. It should be pulled-down on the target PCB.

#### 4.8.3 MCU<sub>TX</sub> and MCU<sub>RX</sub>
- 
MCU<sub>TX</sub> and MCU<sub>RX</sub> are broken out so that the MCU can be emergency flashed. They should be connected to a USART capable of flashing the bootloader.  
- For most STM32 MCU's this is USART1, USART2 or USART3. During normal operation, the USART may be used for debugging.  

---

### 4.9 CAN-FD Connector

Standardised connector across all PCB's for connection to a CAN-FD nodes.

- Connector: Samtec T1M, 3 pin, horizontal, single-row, [SAMTEC-T1M-03-F-SH-L](https://www.samtec.com/products/t1m-03-f-sh-l)
- Height: 4.6mm

| Pin  | Name | Notes |
|---|---|---|
| 1 | CAN<sub>LOW</sub>  | CAN Low |
| 2 | CAN<sub>HIGH</sub> | CAN High |
| 3 | GND | Signal ground |

### 4.9.1 CAN<sub>LOW</sub> and CAN<sub>HIGH</sub>

CAN<sub>LOW</sub> and CAN<sub>HIGH</sub> are a differential signal and should be twisted-pair.

---

## 5. Firmware Architecture

### 5.1 Execution Model

- The primary firmware will be written in C/C++ on a *baremetal* level (HAL is acceptable)  
- Additional nodes may use whatever they like  

---

### 5.4 Update Mechanism

- [ ] USB  
- [ ] CAN  
- [ ] OTA  

- [ ] Secure boot required  

---

## 6. Safety & Fault Handling

### 6.1 Fault Classes

- Sensor failure  
- Actuator failure  
- Power instability  
- Communication loss  
- Internal software fault  

---

### 6.2 Detection Mechanisms

- [x] Watchdogs (independent + windowed)  
- [x] Heartbeats (inter-module)  
- [x] Plausibility checks  

---

### 6.3 Failsafe Behaviour

| Fault | Description | Probability | Response |
|---|---|---|---|
| FAULT001 | Primary IMU failure | LOW | Warn and log |
| FAULT002 | Secondary IMU failure | LOW | Warn and log |
| FAULT003 | All IMU failure | VERY LOW | Catastrophic |
| FAULT004 | GNSS loss | HIGH | No action |
| FAULT005 | RC link loss | HIGH | Usually switch to RTH mode |
| FAULT006 | Critical FCU internal fault | LOW | Restart node |

---

## 7. Performance Targets

- Control loop frequency: 1 kHz  
- End-to-end latency: sub 20 ms  
- Boot time: sub 3 s  
- Max supported nodes (CANFD): 64  
- Max actuator count: 10+  

---

## 8. Environmental Requirements

- Operating temperature: -40C to 120C (low temperature handling is much more important)  
- Vibration tolerance: ___________  
- Shock tolerance: ___________  
- EMC compliance target: ___________  

---

## 9. Security

- [ ] Secure boot  
- [ ] Firmware signing  
- [ ] Encrypted communication  
- [ ] Key storage (secure element?)  

---

## 10. Verification Strategy

- [ ] SIL (software-in-loop)  
- [ ] HIL (hardware-in-loop)  
- [ ] Bench testing  
- [ ] Flight testing  

**Acceptance Criteria:**
- ___________

---

## 11. Integration Model (Critical)

Hermetica must remain **independent of Aetherion** until integration.

### 11.1 Negotiated Parameters

| Parameter | Hermetica Target | Aetherion Constraint | Status |
|---|---|---|---|
| Weight | < 500g | 1.0kg limit | [x] |
| Power | 2S to 8S supply, 500mA total consumption | ___ | [ ] |
| Size | 60mm(W) x 80mm(L) x 50mm(H) | ___ | [ ] |

---

## 12. Open Questions

- What exact role does CAN play — backbone only, or full distributed compute?
- Are you committing to dual-core safety separation, or is that overkill for MVP?
- Is FBUS a first-class interface, or just supported?
- Do you want PX4 compatibility, or is this clean-slate?
- What is the minimum viable flight capability?

---

## 13. MVP Definition

**MVP must include:**
- CANFD working backbone for messaging between stack layers  
- Basic stabilized flight  
- Basic loiter flight mode  
- Gyroscope, accelerometer and magnetometer fusion  
- RC input (SBUS)  
- PWM output for ESC and servos
- Independant control of ailerons, elevators, rudders and flaps  
- Basic failsafe  

**Explicitly excluded:**
- Advanced flight modes  
- Pitot integration  
- Payload ecosystem  
- OSD integration

---

## 14. Future Extensions

- TBC

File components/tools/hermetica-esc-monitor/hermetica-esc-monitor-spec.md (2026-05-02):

# Hermetica ESC / Motor Monitor

## Purpose

Standalone PCB to monitor and control ESC / Motor combinations for testing purposes.

Born out of interaction with T-Motor where they are sending me evaluation hardware. I wish to provide them a good solid dataset in return, aiming for future collaboration. Could also be used for other manufacturers in a similar way.

Not designed to be part of the Hermetica FCU system - but designed to optionally work with it.

The system shall be able to operate on a bench
The system shall be able to operate in an airframe on the ground
The system shall be able to operate in an airframe in the air
The system shall be capable of recording data to SD-card at a rate of 200Hz
The system shall be capable of injecting signal faults into the data stream to the ESC:
- ESC-side signal to GND
- ESC-side signal to 3.3V
- Board-ESC capacitance 
- Board-ESC resistance
Monitoring must be non-invasive and testing should be non-destructive.

## Operating Modes

The system shall be able to operate in a number of distinct modes:
- "Bench Mode", signal generation, requires no external signal from RC Receiver.  
_PCB acts as a signal generator, using specific test profiles._
- Pass-through, for use with a RC Receiver.  
_PCB acts as a signal monitor and logs data only_

## INPUTS

**Power**:
2S to 8S primary battery
5V BEC (integrated with ESC under test)

**ESC Signals**:
PWM from RCRX
UART from RCRX

Note: PWM and UART are on the same physical connector pin.

**External sesnsors:**
Temperature monitoring via NTC
Accelerometer for vibration SPI
RPM pulse

## OUTPUTS

**ESC Signals:**
PWM generated on board (standalone mode)
PWM from RCRX
UART generated on board (standalone mode)
UART from RCRX

Note: PWM and UART are on the same physical connector pin.

Signals from RCRX must be intercepted for timing.

## Example test profiles

Test profiles are only for use in "bench" mode.

All profiles are based upon changing throttle signal.

Profiles stored on SDCard

Examples:

- Baseline (0% to 100% throttle, over 300 seconds)
- Slow ramp (0% to 100% throttle, over 10 seconds)
- Fast ramp (0% to 100% throttle, over 2 seconds)
- Takeoff, cruise, landing (80%, 30%, 10%)
- Instantaneous X% from stop (for detecting spool up speed)
- Instantaneous X% to stop (for detecting spool down speed)
- Sawtooth %X to %Y to %X, repeating

## Definite Hardware
- Additional hardware will be required.
- INA238 - for voltage and current monitoring of PD1
- STM32H755ZIT6 - for control and primary sensor monitoring
- WSL27261L300FEA - current shunt, 3W, 1.3mOhm
- Single LM51606 - primary supply to 5V regulation (600mA)
- TDK VLS5045EX-330M - 33uH coil for LM51606
- Multiple LP5912Q3.3 - 5V to 3.3V local point regulation for each on board power domain
- SMBJ36A - TVS across supply for some protection
- BAT60J - standard schottky
- IIS3DWBG1TR - accelerometer, fixed to motor mount on small PCB for measuring vibration  
- SN74LVC1G17 for signal buffering where needed
- SN74LVC1G3157 SPDT analogue switch for signal routing

## External optical RPM sensor
- [Needs fleshing out]
- Minimal BOM, keep PCB as small as possible
- Will have to fit inside airframe nacel - limited space
- Ideally operates at 3.3V and provides a 3.3V pulse output
- Provides pulse when reflection detected
- Buffered on monitoring board before being fed to a timer capture

## External accelerometer 

Small external square PCB drilled to fit a standard X shaped motor mount. IIS3DWBG1TR in the centre communicating via SPI. Designed to fit between the motor mount and the engine "firewall" (usually a wooden plate in RX airframes). Could also be mounted to the firewall instead. Short length (<20cm) connection to the main PCB carrying:

- 5.0V from PD2
- GND
- SPI_CLK
- SPI_MISO
- SPI_MOSI
- SPI_CS
- INT1
- INT2

Local 5.0V supply through local LDO to 3.3V due to extremely noisy environment. PCB will be placed next to the motor, less than 2cm from the windings.
Could be left in place in airframe. The weight will be negligible.

- Uses 4-wire SPI, not I2C
- PCB 43.18mm x 43.18mm (1.6mm thick)
- Copper top and bottom with large GND pours
- Need to consider via-wall strategy around IIS3DWBG1TR 
- Single-sized assembly
- Tallest component 0805 sized SMD capacitor
- Series resistors (22R) on SPI_MISO, INT1, INT2
- Pullup on SPI_CS (10K)
- SMD capacitors sized at 0805
- SMD resistors sized at 0603
- Onboard LDO regulation of 5.0V supply to 3.3V via LP5912Q3.3
- IIS3DWBG1TR placed in exact centre of PCB
- 4 x 4.3mm mounting holes drilled in corners of PCB to match motor mount
- Keep-out zones around mounting holes
- Small LED for power indication for easy visual inspection
- Capacitors/resistors sized to avoid physical damage from vibrations
- INT1 and INT2 configured as push-pull, not open-drain

## External lines to have 22R series resistors

- SPI_CLK (close to MCU)
- SPI_CS (close to MCU)
- INT1 from accelerometer (close to accelerometer)  
- INT2 from accelerometer (close to accelerometer)  
- RPM input pulse (close to MCU)

## Power Domains

- **PD1 (2S to 8S)**   
Primary power from 2S to 8S battery.
Passes through PCB mounted shunt resistor before feeding ESC (high-side monitoring).
Will be noisy and have large transients.
Physically connected to PCB by AWG10 wire and M2.5 mounting holes (through hole to all copper layers).

- **PD2 (5.0V)**  
PD1 -> LP51606 -> PD2
5V power from LP51606, max 600mA.
Slightly less noisy that PD1 but still not great.
Delivered through BAT60J to prevent backfeeding to 5V rail.
Suitable for post-regulation.

- **PD3 (3.3V)**  
PD2 -> LP5912Q3.3 (1) -> PD3
3.3V power for MCU digital domain.
Filtered.
Directly powers MCU and digital peripherals.

- **PD4(3.3V)**  
PD2 -> LP5912Q3.3 (2) -> PD4
3.3V power for MCU analogue domain.
Filtered.
Should be _very_ clean.

## Monitoring Metrics

Average Current during 5ms Window
Peak Current during 5ms Window
Average Primary Voltage during 5ms Window
Minimum Primary Voltage during 5ms Window (to monitor voltage sag)
Motor Temperature (stator probably easier than windings)
ESC Temperature
Ambiant temperature (for calculating esc/motor temp rise)
Vibration

RPM derived from timestamped pulse intervals, resampled into the 200Hz dataset.

Temperature measurement is slow and approximate. The delta (rise) is more important than the absolute value.

## Recording @ 200Hz

All metrics recorded at same rate, regardless of their update speed.
Writing handled by M4 core. Data streamed to local microSD-card, with dual circular buffers and DMA.

## Bench vs Monitoring mode
- Configured by physical jumper
- Defaults to Monitoring mode if no jumper fitted

## Safety Limits
Only enforced in bench mode, Monitoring Mode just allows the board or device to fail. This is a design decison.

Mitigating factors:
- It is assumed the ESC and motor will be bench-tested before flight
- It is assumed the airframe will be flown within normal operational limits
- It is assumed the airframe will not be cause the limits determined by bench testing to be exceeded

### System design limits
- Global limits per board:
  - Maximum shunt temperature
  - Maximum shunt current
- LED indication of approaching 90% of system limit
- Performs graceful stop of currently executing test profile when limit reached for safety

### Device Under Test (DUT) limits
- Specific limits per device:
  - Maximum ESC temperature
  - Maximum Motor temperature
  - Maximum shunt current
  - Maximum RPM
- LED indication of approaching 90% of DUT limit
- Performs graceful stop of currently executing test profile when limit reached for safety

## Control flow

**Bench Mode**
- MCU generates PWM or UART signal
- 2:1 Analogue switch routes MCU output to fault network
- Fault network routes signal to ESC

**Monitoring Mode**
- External RC receiver generates PWM or UART signal
- Signal is buffered in parallel for monitoring while the primary path remains independent.
    - Primary path routed to ESC
    - Parallel path buffer via SN74LVC1G17 and routed to either MCU TIMx capture input or UARTx_RX via 2:1 analogue switch
- Fault network completely bypassed

**Jumpers: JP1 - Operating Mode Selection**
- Low : Monitoring Mode (Default if not fitted)
- High: Bench Mode

**Jumpers: JP2 - Signal Type Selection**
- Low : PWM (Default if not fitted)
- High: UART

**Analogue Switches: SW1**
- JP1 = Low/Not Fitted
- Switch controlled by JP2
- 2:1
- Position 1: Incoming signal -> MCU TIMx capture input
- Position 2: Incoming signal -> MCU UARTx_RX

**Analogue Switches: SW2**
- JP1 = High
- Switch controlled by JP2
- 2:1
- Position 1: MCU TIMx output -> Fault Network
- Position 2: MCU UARTx_TX -> Fault Network

**Routing Table**
| JP1 | JP2 | SW1 | SW2 |
|-----|-----|-----|-----|
| L | L | Routes incoming signal to MCU TIMx capture input in parallel to ESC | _Unused_ |  
| L | H | Routes incoming signal to MCU UARTx_RX in parallel to ESC | _Unused_ |  
| H | L | _Unused_ | Routes MCU TIMx output to Fault network |  
| H | H | _Unused_ | Routes MCU UARTx_TX to Fault Network |  

## MCU ADC Peripheral Usage

| Peripheral | Channel | Usage |
|---|---|---|
| ADC1 | IN2 | BEC Voltage |
| ADC1 | IN3 | ESC Temperature |
| ADC1 | IN4 | motor Temperature |
| ADC1 | IN5 | Ambiant Temperature  |
| ADC1 | IN6 | Shunt Temperature |
| ADC1 | IN7 | Spare / Unused |

## Fault injection
- Only in Bench Mode

### GND -> SIGNAL_OUT
- Controlled by GPIO to N-FET
- Gate pulled down by default

### 3.3V -> SIGNAL_OUT
- Controlled by GPIO to N-FET
- Gate pulled down by default

### Signal IN -> resistance -> SIGNAL_OUT
- 1:2 switch controlled by GPIO

### Signal IN -> capacitance -> SIGNAL_OUT
- 1:2 switch controlled by GPIO

### Signal IN -> capacitance to GND -> SIGNAL_OUT
- 1:2 switch controlled by GPIO

### Hi-Z -> SIGNAL_OUT
- Analogue switch with disable

Hardware-controlled analogue switching network. For testing ESC integrity (NOT in the air!).

Fault injection to be last stage before signal sent to ESC.

## BEC Voltage monitoring

- Voltage monitoring of ESC BEC, through a fixed load to check for voltage sag under ESC throttle changes. Could potentially very useful data for manufacturers if I can get it working. Perhaps a fixed 500mA load on PCB with heatsink. Check how BEC voltage performs at high ESC dI/dt.

- Monitored via a voltage divider into an ADC channel

## External sync
- Still need to determine how it works
- Basic idea is to reset internal timers on sync pulse rising edge
- Single pulse enough or repeated periodic ones to remain in sync?
- How to determine master / slave? Wiring? Each board has SYNC_IN (slave) and SYNC OUT (master)?

## Main questions at present

- Decide how to load the BEC
- Best way to design a miniature temperature probe for measuring motor stator temperature
- MCU pinout:
  - MCU timers for signal generation and capture (TIM1 / TIM8)
  - ideal pins for PWM capture and generation
- 16MHz MCU timing crystal selection and tuning caps
- Best MCU clock speed (try 200MHz and tune)
- ADC is needed for reading temperatures via voltage dividers. Anything else? BEC voltage?
- SDCard hardware considerations (I've never designed a board with one before - learning curve).
  - Use SDMMC peripheral not SPI
  - What pullups/pulldowns on which pins?
  - Decoupling caps? - 10uF and 100nF close to card supply.
  - How to handle card-detect? Pull up or pull down?
  - 22R series resistors close to MCU pins on all data and clock lines

## 

- Should fit a standard "Hermetica-class" CAN-FD chain to the PCB, due to T-Motor's interest in CAN. No need to write any firmware. Hardware can just sit there doing nothing in case it's needed in future. Very small price to pay for future proofing.

## Future considerations

- Consider ways to use baseline thrust-curve in the air if FCU connected via CAN.

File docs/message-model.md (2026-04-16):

## CAN-FD Message Model

### Overview

The Hermetica CAN-FD message model defines a deterministic, scalable, and role-aligned communication architecture for all Flight Stack Layers and external Nodes.

The model is designed to:
- Ensure predictable timing and latency
- Maintain clear data ownership
- Enable fail-operational behaviour
- Scale to 64+ nodes without degradation

---

### Design Principles

- Publisher-based architecture (no polling for critical data)
- Time-triggered delivery for flight-critical messages
- Event-triggered delivery for asynchronous conditions
- Strict ownership of data
- No ambiguity in message meaning
- Deterministic scheduling over CAN-FD

---

### Message Classes

All messages shall belong to exactly one class.

| Class | Purpose | Timing | Priority |
|---|---|---|---|
| COMMAND | Control inputs and targets | Periodic | Highest  |
| STATE | System and sensor state | Periodic | High |
| STATUS  | Health and diagnostics | Periodic | Medium |
| EVENT | Faults and transitions | Asynchronous  | Highest  |
| CONFIG  | Configuration and params | On-demand | Low |
| DEBUG | Development and logging | Opportunistic | Lowest |

---

### CAN Identifier Structure (29-bit Extended)

All messages shall use extended (29-bit) CAN identifiers.

#### Bit Layout

| Field | Bits |
|---|---|
| Priority | 3 |
| Class | 3 |
| Source Node  | 7 |
| Message Type | 8 |
| Instance | 8 |

#### Field Definitions

- Priority: Lower value = higher priority (CAN arbitration)
- Class: Message class identifier
- Source Node: Unique node ID (0–127)
- Message Type: Defines payload meaning
- Instance: Identifies multiple instances (e.g. IMU1, IMU2)

---

### Node Identity Model

Each node shall have a unique Node ID.

#### Reserved Node IDs

| Node ID  | Description |
|---|---|
| 0x00 | Flight Control Board |
| 0x01 | Power Management |
| 0x02–0x0F | Core Stack Layers |
| 0x10–0x7F | External Nodes |

---

### Message Types

#### COMMAND Messages

Ownership: Flight Control Role  
Priority: Highest  
Timing: Periodic

| Type ID | Name | Description |
|---|---|---|
| 0x01 | Actuator Command | Final actuator outputs |
| 0x02 | Attitude Target  | Roll, pitch, yaw |
| 0x03 | Rate Target | Angular rates |

Requirements:
- Fixed interval transmission
- No request/response
- No delays

---

#### STATE Messages

Ownership: Sensor Processing Role  
Priority: High  
Timing: Periodic

| Type ID | Name | Description |
|---|---|---|
| 0x10 | IMU State | Accel + gyro |
| 0x11 | Attitude Estimate | Fused orientation |
| 0x12 | Position Estimate | GNSS position |
| 0x13 | Air Data | Airspeed + pressure |

---

#### STATUS Messages

Ownership: Each node  
Priority: Medium  
Timing: Periodic

| Type ID | Name | Description |
|---|---|---|
| 0x20 | Node Health | OK/WARN/FAIL |
| 0x21 | Power Status | Voltage, current |
| 0x22 | Actuator Status | Feedback |

---

#### EVENT Messages

Ownership: Any node  
Priority: Highest  
Timing: Asynchronous

| Type ID | Name | Description |
|---|---|---|
| 0x30 | Fault Raised | Fault detected |
| 0x31 | Fault Cleared | Fault cleared |
| 0x32 | Mode Change | Flight mode change |
| 0x33 | Arming State Change  | Armed/disarmed |

Requirements:
- Immediate transmission
- Rate-limited

---

#### CONFIG Messages

Ownership: System Management / Ground Interface  
Priority: Low  
Timing: On-demand

Used for:
- Parameter read/write
- Node configuration

Allows request/response.

---

#### DEBUG Messages

Ownership: Any node  
Priority: Lowest  
Timing: Opportunistic

Used for:
- Logging
- Debugging

Constraints:
- Must be droppable
- Must be rate-limited
- Disabled in flight

---

### Payload Design Rules

- Fixed-size structures preferred
- No dynamic allocation
- No strings
- Packed binary format
- Consistent units across system

#### Example: Actuator Command

```c
struct {
  int16_t throttle;
  int16_t roll;
  int16_t pitch;
  int16_t yaw;
  int16_t flaps;
  int16_t differential_throttle;
};
```

---

### Timing Model

#### Update Rates

| Data Type | Rate |
|---|---|
| IMU | 1000 Hz |
| Attitude | 500 Hz |
| Actuator Command | 500–1000 Hz |
| GNSS | 10 Hz |
| Status | 10–50 Hz |

---

### Synchronisation

- Global SYNC signal required
- All nodes align to SYNC
- Messages transmitted in defined time slots

---

### Example Schedule

| Time (ms) | Message |
|---|---|
| 0.0 | IMU State |
| 0.5 | Attitude Estimate  |
| 1.0 | Actuator Command |
| 2.0 | Status |

---

### Bus Load Strategy

- High-rate messages restricted to core stack
- External nodes use lower rates
- Debug traffic disabled during flight

---

### Fault Handling

#### Detection

- Missing periodic messages = fault
- No ACK required

#### Behaviour

- Consumers implement timeouts
- System degrades gracefully

---

### Determinism Rules

- No blocking on CAN
- No request/response in critical paths
- All critical data is publisher-driven
- Timing must be bounded and predictable

---

### Summary

This model provides:
- Deterministic communication
- Clear ownership of data
- Predictable behaviour
- Scalable distributed architecture

---

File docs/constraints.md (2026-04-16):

# Project Hermetica – Design Constraints

**Version:** 0.1  
**Date:** 2026-04-16  
**Owner:** Daniel Johnson  
**Status:** Draft  

---

## 1. Scope

This document defines the design constraints for Project Hermetica.

---

## 2. Constraints

| ID | Origin | Constraint |  Notes | 
|---|---|---|---|
| DC-001 | Environment  | Air temperature at 20000ft can be as low as -25C | |  
| DC-002 | Environment  | Ground temperature can be as high as 50C | |  
| DC-003 | Power System | Primary battery minimum voltage is 6.4V | Electrical input lower limit | 
| DC-004 | Power System | Primary battery maximum voltage is 33.6V | Electrical input upper limit |  
| DC-005 | Airframe A | Has a dry weight of 1.3kg | |  
| DC-006 | Airframe A | Has a MTOW of 5.5kg | |  
| DC-007 | Airframe A | Has a RTOW of 4.0kg | |  
| DC-008 | Airframe A | Has ailerons requiring two servos | |  
| DC-009 | Airframe A | Has airbrakes requiring two servos | |  
| DC-010 | Airframe A | Has an engine layout supporting differential thrust | |  
| DC-011 | Airframe A | Has canards requiring two servos | |  
| DC-012 | Airframe A | Has elevators requiring two servos | |  
| DC-013 | Airframe A | Has elevons requiring two servos | |  
| DC-014 | Airframe A | Has flaps requiring two servos | |  
| DC-015 | Airframe A | Has landing gear requiring one servo | |  
| DC-016 | Airframe A | Has rudders requiring two servos | |  
| DC-017 | Airframe A | Has ruddervators requiring two servos | |  
| DC-018 | Airframe A | Has space for a FCU of 150mm x 130mm x 80mm | |  
| DC-019 | Airframe A | Has symmetric engines requiring two ESC's | |  
| DC-020 | Airframe A | Is a fixed-wing airframe in V-Tail configuration | |  
| DC-021 | Airframe A | Requires hand launching | Airframe may undergo rapid acceleration and mechanical stress | 
| DC-022 | Airframe B | Has a dry weight of 1.3kg | |  
| DC-023 | Airframe B | Has a MTOW of 5.5kg | |  
| DC-024 | Airframe B | Has a RTOW of 4.0kg | |  
| DC-025 | Airframe B | Has an engine layout supporting differential thrust | |  
| DC-026 | Airframe B | Has flaperons requiring two servos | |  
| DC-027 | Airframe B | Has ruddervators requiring two servos | |  
| DC-028 | Airframe B | Has space for a FCU of 130mm x 130mm x 60mm | |  
| DC-029 | Airframe B | Has symmetric engines requiring four ESC's | |  
| DC-030 | Airframe B | Is a fixed-wing airframe in V-Tail configuration | |  
| DC-031 | Airframe B | Requires hand launching | Airframe may undergo rapid acceleration and mechanical stress | 
| DC-032 | Airframe C | Has a dry weight of 1.3kg | |  
| DC-033 | Airframe C | Has a MTOW of 4.5kg | |  
| DC-034 | Airframe C | Has a RTOW of 3.0kg | |  
| DC-035 | Airframe C | Has a single engine requiring one ESC | |  
| DC-036 | Airframe C | Has ailerons requiring two servos | |  
| DC-037 | Airframe C | Has an elevator requiring one servo | |  
| DC-038 | Airframe C | Has flaps requiring two servos | |  
| DC-039 | Airframe C | Has a rudder requiring one servo | |  
| DC-040 | Airframe C | Has space for a FCU of 70mm x 60mm x 50mm | |  
| DC-041 | Airframe C | Is a fixed-wing airframe in T-Tail configuration | |  
| DC-042 | Airframe C | Requires hand launching | Airframe may undergo rapid acceleration and mechanical stress | 
| DC-043 | ESC A | Has a PWM interface | |  
| DC-044 | ESC B | Has an SBUS interface | |  
| DC-045 | ESC B | Has an SBUS2 interface | |  
| DC-046 | ESC C | Has an FBUS interface | |  
| DC-047 | Receiver A | Has a PWM interface | |  
| DC-048 | Receiver B | Has an SBUS interface | |  
| DC-049 | Receiver C | Has an SBUS2 interface | |  
| DC-050 | Receiver D | Has an FBUS interface | |  
| DC-051 | Servo A | Has a PWM interface | |  
| DC-052 | Servo A | Has an SBUS interface | |  
| DC-053 | Servo A | Has an SBUS2 interface | |  
| DC-054 | Servo A | Has an FBUS interface | |  

---

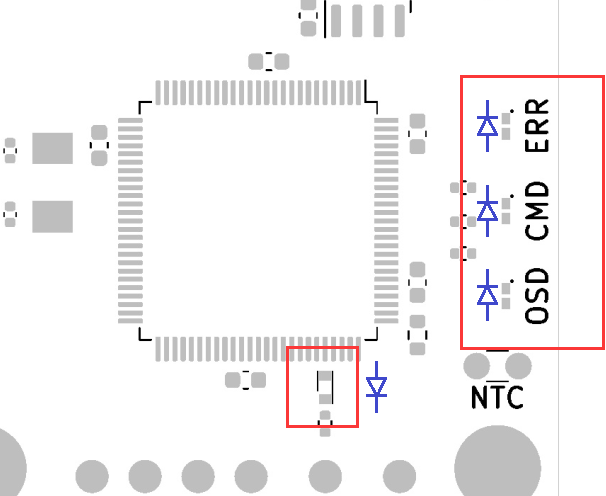
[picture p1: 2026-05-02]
components/osd-v4/hardware/pic2-with-cathodes.png

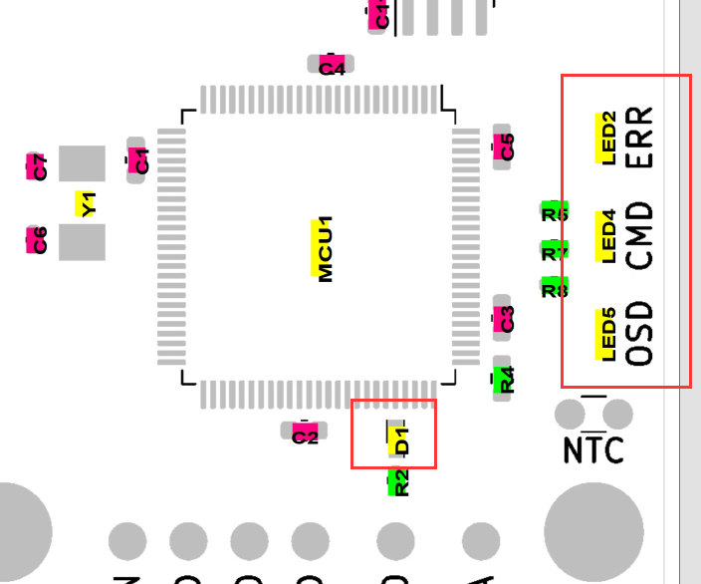
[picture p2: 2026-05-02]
components/osd-v4/hardware/pic1.png

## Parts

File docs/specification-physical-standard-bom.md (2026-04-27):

# Project Hermetica – Physical System Specification

## Physical System

### Standardised Bill of Materials

| Type | Manufacturer | Part Number | Package | Usage |
|---|---|---|---|---|
| Microcontroller | STM | STM32H755ZIT6 | LQFP-144 20x20x1.4 | High speed compute |
| Microcontroller | STM | STM32G484CET6 | LQFP-48 7x7x1.4 | Low speed compute |
| CAN-FD Transceiver | TI | TCAN3403-Q1 | | CAN-FD |
| ESD Protection | Nexperia | PESD2CANFD24V-QCZ | | CAN-FD ESD Protection |
| Voltage Regulation | TI | TPSM63603 | | 8S to 5.0V 3A bus regulation |
| Voltage Regulation | TI | LP5912Q3.3 | | 5V to 3.3V 500mA point regulation  |
| Choke | TDK | ACT1210D1012PTL00 | | CAN-FD |
| Diode | STM | BAT60FILM | | General |
| FRAM | Fujitsu | MB85RS1MT | | SPI Configuration storage |
| Tri-State Gate | TI | SN74LVC1G125 | | Actuator node hardware interlock |  
| Schmitt Buffer | TI | SN74LVC1G17 | | Signal buffering |  

---

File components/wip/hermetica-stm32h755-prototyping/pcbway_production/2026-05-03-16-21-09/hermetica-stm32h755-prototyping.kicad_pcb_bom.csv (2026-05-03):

Designator | Quantity | Value | Footprint | Package | MPN | DNP | Mount_Type
C1 | 1 | 22nF | C_0402_1005Metric |  |  |  | smt
C10 | 1 | 1uF | C_0402_1005Metric |  |  |  | smt
C11, C13, C14, C15, C16, C17, C18, C19, C20, C21, C22, C23, C24, C25, C26, C27, C28, C29, C30, C33 | 20 | 100nF | C_0402_1005Metric |  |  |  | smt
C12 | 1 | 4.7uF | C_0402_1005Metric |  |  |  | smt
C2 | 1 | 10pF | C_0402_1005Metric |  |  |  | smt
C3, C4, C5, C6, C7, C8 | 6 | 2.2uF | C_0402_1005Metric |  |  |  | smt
C31, C32 | 2 | 10uF | C_0805_2012Metric |  |  |  | smt
C34, C35, C36 | 3 | 1uF | C_0603_1608Metric |  |  |  | smt
C37, C38 | 2 | 1uF | C_0805_2012Metric |  |  |  | smt
C9 | 1 | 10uF | C_0402_1005Metric |  |  |  | smt
D1 | 1 | BAT60JFILM | STM-BAT60JFILM-SOT-323-2 |  |  |  | smt
D2, D3 | 2 | ESDA7P60-1U1M | STM-ESDA7P60-1U1M |  |  |  | smt
FB1 | 1 | L_Bead | L_0402_1005Metric |  |  |  | smt
IC1 | 1 | FUJITSU-MB85RC64TAPN | FUJITSU-MB85RC64TAPN-SON8 |  |  |  | smt
J1, J100, J101, J102, J103, J104, J105, J106, J107, J108, J109, J110, J111, J112, J113, J114, J115, J116, J117, J118, J119, J120, J121, J122, J123, J124, J125, J126, J127, J128, J129, J130, J131, J132, J133, J134, J135, J136, J137, J138, J139, J140, J141, J142, J147, J148, J149, J150, J151, J18, J19, J2, J20, J21, J22, J23, J24, J25, J26, J27, J28, J29, J3, J30, J31, J32, J34, J35, J37, J38, J4, J40, J41, J42, J43, J44, J45, J46, J47, J48, J49, J5, J50, J51, J52, J53, J54, J55, J56, J57, J58, J59, J6, J60, J61, J62, J63, J64, J65, J66, J67, J68, J69, J70, J71, J72, J73, J74, J75, J76, J77, J78, J79, J80, J81, J82, J83, J84, J85, J86, J87, J88, J89, J90, J91, J92, J93, J94, J95, J96, J97, J98, J99 | 133 | Conn_01x01 | CONNECTOR-PCB-HANDSOLDER-01X01-FEMALE |  |  |  | tht
J17 | 1 | CONNECTOR-DEBUG-SPECIFIC-ARM | PinHeader_2x05_P1.27mm_Vertical_SMD |  |  |  | smt
LED1, LED2, LED3, LED5 | 4 | KINGBRIGHT-LED-0402-ORANGE | KINGBRIGHT-LED-APHHS1005-0402 |  |  |  | smt
LED10, LED11 | 2 | APHB1608CGKSURKC | KINGBRIGHT-APHB1608CGKSURKC |  |  |  | smt
LED4, LED6 | 2 | KINGBRIGHT-LED-0402-RED | KINGBRIGHT-LED-APHHS1005-0402 |  |  |  | smt
MCU1 | 1 | STM-STM32H755ZITx | LQFP-144_20x20mm_P0.5mm |  |  |  | smt
Q1, Q2, Q3, Q4 | 4 | DIODESINC-MMBT4401-7-F-SOT-23-3 | SOT-23-3 |  |  |  | smt
R1, R2, R3 | 3 | 22R | R_0402_1005Metric |  |  |  | smt
R10, R11, R12, R30, R31, R32, R33, R7, R8, R9 | 10 | ? | R_0402_1005Metric |  |  |  | smt
R13, R14, R15, R16 | 4 | 47K | R_0402_1005Metric |  |  |  | smt
R17, R18, R19, R20, R21, R4, R5 | 7 | 10K | R_0402_1005Metric |  |  |  | smt
R22, R23 | 2 | 20K | R_0402_1005Metric |  |  |  | smt
R6 | 1 | 1K | R_0402_1005Metric |  |  |  | smt
SW1 | 1 | B3U1000PM | OMRON-B3U-1000PM |  |  |  | smt
U1 | 1 | LD1117S50TR_SOT223 | SOT-223-3_TabPin2 |  |  |  | smt
U3, U4 | 2 | LM66100DCK | SOT-363_SC-70-6 |  |  |  | smt
U5 | 1 | AP2112K-3.3 | SOT-23-5 |  |  |  | smt
Y1 | 1 | ABRACON-ABM10AIG-48.000MHZ-4Z-T3 | ABRACON-ABM10AIG |  |  |  | smt
Y2 | 1 | ABRACON-ABS07-LR-32.768KHZ-6-1-T | ABRACON-ABS07-LR |  |  |  | smt

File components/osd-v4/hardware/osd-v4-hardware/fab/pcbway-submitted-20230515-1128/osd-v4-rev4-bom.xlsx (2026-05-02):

Id | Designator | Quantity | Manufacturer | *Mfg Part # | Description / Value | Mouser Part# | Footprint
1 | C1,C2,C3,C4,C5,C9,C11,C12 | 8 |  |  | SMD CAPACITOR 0603 100nF X7R 10V |  | SMD 0603
2 | C6,C7 | 2 |  |  | SMD CAPACITOR 0402 22pF X7R 10V |  | SMD 0402
3 | C8,C10 | 2 |  |  | SMD CAPACITOR 0402 100nF X7R 10V |  | SMD 0402
4 | D1 | 1 | DIODES INCORPORTATED | 1N4148WTQ-7 | SMD DIODE SOD52 | 621-1N4148WTQ-7 | SMD SOD523
5 | IC1 | 1 | TEXAS INSTRUMENTS | LM1881M/NOPB | SMD IC LM1881 | 926-LM1881M/NOPB | SMD SOIC8
6 | IC2 | 1 | TEXAS INSTRUMENTS | ISO7321FCDR | SMD IC ISO7321FC | 595-ISO7321FCDR | SMD SOIC8
7 | J2 | 1 | SAMTEC | SMA-J-P-H-RA-TH1 | THT RF CONNECTOR RIGHT ANGLE 50ohm 6GHz | 200-SMAJPHRATH1 | THT
8 | J3 | 1 | AMPHENOL FCI | 10129381-906004BLF | THT 2X3 P2.54 PINHEADER MALE VERTICAL | 649-1012938190604BLF | THT
9 | LED2 | 1 | KINGBRIGHT | APHHS1005SURCK | SMD LED 0402 RED VF=1.95V | 604-APHHS1005SURCK | SMD 0402
10 | LED4,LED5 | 2 | KINGBRIGHT | APHHS1005CGCK | SMD LED 0402 GREEN VF=2.1V | 604-APHHS1005CGCK | SMD 0402
11 | MCU1 | 1 | MICROCHIP | ATMEGA2560-16AU | SMD IC ATMEGA2560 TQFP100 | 556-ATMEGA2560-16AU | SMD TQFP100
12 | R1,R4 | 2 |  |  | SMD RESISTOR 0603 10K 10% |  | SMD 0603
13 | R2 | 1 |  |  | SMD RESISTOR 0402 330R 10% |  | SMD 0402
14 | R3 | 1 |  |  | SMD RESISTOR 0402 680K 10% |  | SMD 0402
15 | R7,R5,R8 | 3 |  |  | SMD RESISTOR 0402 145R 10% |  | SMD 0402
16 | RV1 | 1 | BOURNS | PVG3A104C01R00 | SMD TRIMMER RESISTOR 100K 20% | 81-PVG3A104C01R00 | SMD PVG3
17 | Y1 | 1 | ABRACON | ABM3-16.000MHZ-D2Y-T | SMD CRYSTAL ABM3 16MHZ 18PF | 815-ABM3-16-D2Y-T | SMD ABM3

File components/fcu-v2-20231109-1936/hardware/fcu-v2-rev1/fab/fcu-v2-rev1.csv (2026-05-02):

Id | Designator | Quantity | Manufacturer | Mfg Part # | Description / Value | Mouser Part # | Footprint | Mounting
1 | U2,U3 | 2 | ANALOG DEVICES | LT1129CST-3.3#TRPBF | SMD IC LDO 3.3V SOT223 | 584-1129CST-3.3TRPBF | SMD SOT-223-3 | SMD
22 | SW1 | 1 | CUI DEVICES | TS04-66-65-BK-100-SMT | SMD SWITCH TACTILE CUI-TS04 | 179-TS046665BK100SMT | CUI-TS04-SWITCH | SMD
3 | J23 | 1 | HARWIN | M50-3600542R | SMD PinHeader_2x05_P1.27mm_Vertical | 855-M50-3600542R | PinHeader_2x05_P1.27mm_Vertical_SMD | SMD
11 | LED1,LED2,LED3,LED4 | 4 | KINGBRIGHT | APHHS1005CGCK | SMD LED 0402 GREEN VF=2.1V | 604-APHHS1005CGCK | KINGBRIGHT-LED-APHHS1005-0402 | SMD
17 | LED5 | 1 | KINGBRIGHT | APHHS1005SECK | SMD LED 0402 ORANGE VF=2.1V | 604-APHHS1005SECK | KINGBRIGHT-LED-APHHS1005-0402 | SMD
16 | LED6 | 1 | KINGBRIGHT | APHHS1005SURCK | SMD LED 0402 RED VF=1.95V | 604-APHHS1005SURCK | KINGBRIGHT-LED-APHHS1005-0402 | SMD
20 | U1 | 1 | NXP | PCA9685PW,112 | SMD IC I2C PWM DRIVER | 771-PCA9685PW,112 | SMD TSSOP28 | SMD
25 | IC1 | 1 | STM | A3G4250DTR | SMD IC GYROSCOPE LGA16 | 511-A3G4250DTR | SMD LGA16 | SMD
14 | IC2 | 1 | STM | LIS2HH12TR | SMD IC ACCELEROMETER 3-AXIS LGA12 | 511-LIS2HH12TR | SMD LGA12 | SMD
19 | IC3 | 1 | STM | ASM330LHHXTR | SMD IC IMU 6-AXIS LGA14L | 511-ASM330LHHXTR | SMD LGA14L | SMD
21 | IC4 | 1 | STM | IIS2MDCTR | SMD IC MAGNETOMETER 3-AXIS LGA12 | 511-IIS2MDCTR | SMD LGA12 | SMD
7 | IC5 | 1 | STM | ILPS22QSTR | SMD IC BAROMETER LGA10 | 511-ILPS22QSTR | SMD LGA10 | SMD
6 | MCU1 | 1 | STM | STM32H723VGT6 | SMD IC MCU STM32H723VGT6 | 511-STM32H723VGT6 | SMD LQFP100-14X14X1.4 | SMD
2 | C12,C28,C14,C22,C10,C4,C15,C25,C6,C16,C1,C27,C18,C8,C26,C21,C9,C17,C11 | 19 |  |  | SMD CAPACITOR 0402 100nF X7R 10V |  | SMD 0402 | SMD
24 | C13 | 1 |  |  | SMD CAPACITOR 0402 4.7uF X7R 10V |  | SMD 0402 | SMD
18 | C2,C3 | 2 |  |  | SMD CAPACITOR 0402 2.2uF X7R 10V |  | SMD 0402 | SMD
10 | C20,C19 | 2 |  |  | SMD CAPACITOR 0402 10uF X7R 10V |  | SMD 0402 | SMD
12 | C23 | 1 |  |  | SMD CAPACITOR 0402 10nF X7R 10V |  | SMD 0402 | SMD
15 | C24 | 1 |  |  | SMD CAPACITOR 0402 470nF X7R 10V |  | SMD 0402 | SMD
4 | C32,C30,C31,C29 | 4 |  |  | SMD CAPACITOR 0805 10uF X5R 10V |  | SMD 0805 | SMD
9 | C5,C7 | 2 |  |  | SMD CAPACITOR 0402 1uF X7R 10V |  | SMD 0402 | SMD
23 | R12 | 1 |  |  | SMD RESISTOR 0402 68R 10% |  | SMD 0402 | SMD
5 | R5,R6,R7,R4,R2,R1,R3 | 7 |  |  | SMD RESISTOR 0402 10K 10% |  | SMD 0402 | SMD
13 | R8 | 1 |  |  | SMD RESISTOR 0402 147R 10% |  | SMD 0402 | SMD
8 | R9,R10,R11,R13 | 4 |  |  | SMD RESISTOR 0402 60R4 10% |  | SMD 0402 | SMD

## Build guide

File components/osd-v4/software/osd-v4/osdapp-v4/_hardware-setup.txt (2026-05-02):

OSD v4

Hardware Configuration

ATMEGA2560

PA7		GPIO		INJECT
PD0		INT0		LM1881-VSYNC
PD4		ICP1		LM1881-HSYNC
PH0		RX2			ISO7321-TX
PH1		TX2			ISO7321-RX
PJ0		RX3			VTX-SA
PJ1		TX3			VTX-SA
PK0		GPIO		LED1
PK1		GPIO		LED2
PK2		GPIO		LED3

Don't forget to set two fuses:
LOW.CKDIV8		(unticked)
LOW.SUT_CKSEL	Bottom option, long startup, external oscillator with 8MHz+

All other fuses can be left as default

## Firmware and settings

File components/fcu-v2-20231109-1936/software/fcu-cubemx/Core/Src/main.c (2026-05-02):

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
/* Includes ------------------------------------------------------------------*/
#include "main.h"

/* USER CODE BEGIN Includes */
#include "stdio.h"
#include "stdint.h"
#include "string.h"
#include "stm32h7xx_hal.h"
#include "stm32h7xx_hal_uart.h"
#include "stm32h7xx_hal_uart_ex.h"
#include "application.h"
#include "_text.h"
#include "interrupts.h"
/* USER CODE END Includes */


I2C_HandleTypeDef hi2c4;
I2C_HandleTypeDef hi2c5;

TIM_HandleTypeDef htim3;

UART_HandleTypeDef huart4;
UART_HandleTypeDef huart5;
UART_HandleTypeDef huart7;
UART_HandleTypeDef huart2;
UART_HandleTypeDef huart10;

void SystemClock_Config(void);
static void MPU_Initialize(void);
static void MPU_Config(void);
static void MX_GPIO_Init(void);
static void MX_I2C5_Init(void);
static void MX_I2C4_Init(void);
static void MX_UART4_Init(void);
static void MX_UART7_Init(void);
static void MX_UART5_Init(void);
static void MX_USART10_UART_Init(void);
static void MX_USART2_UART_Init(void);
static void MX_TIM3_Init(void);
/* USER CODE BEGIN 0 */

void FAIL(void)
{
	debugWriteError(textClassNameCInterrupts, __LINE__, textFaultHard);
	HAL_GPIO_WritePin(GPIOC, GPIO_PIN_10, GPIO_PIN_RESET);
	HAL_GPIO_WritePin(GPIOC, GPIO_PIN_11, GPIO_PIN_RESET);
	HAL_GPIO_WritePin(GPIOC, GPIO_PIN_12, GPIO_PIN_SET);
	while (1);
}
void ASSERT(int condition)
{
	if (condition == 0)
		FAIL();
}
/* USER CODE END 0 */

/**
  * @brief  The application entry point.
  * @retval int
  */
int main(void)
{
  /* MCU Configuration--------------------------------------------------------*/

  /* Reset of all peripherals, Initializes the Flash interface and the Systick. */
  HAL_Init();

  /* MPU Configuration--------------------------------------------------------*/
  MPU_Config();

  /* Configure the system clock */
  SystemClock_Config();

  /* Initialize all configured peripherals */
  MX_GPIO_Init();
  MX_I2C5_Init();
  MX_I2C4_Init();
  MX_UART4_Init();
  MX_UART7_Init();
  MX_UART5_Init();
  MX_USART10_UART_Init();
  MX_USART2_UART_Init();
  MX_TIM3_Init();
  /* USER CODE BEGIN 2 */

  // configure global debugging...
  debugSetUart(&huart4);

  // ensure nvic interrupts are enabled...
  //__enable_irq();

  // enable uart interrupts...
  huart2.Instance->CR1  |= USART_CR1_RXNEIE;
  huart4.Instance->CR1  |= USART_CR1_RXNEIE;
  huart5.Instance->CR1  |= USART_CR1_RXNEIE;
  huart7.Instance->CR1  |= USART_CR1_RXNEIE;
  huart10.Instance->CR1 |= USART_CR1_RXNEIE;

  // start timer3...
  HAL_TIM_Base_Start(&htim3);

  // jump to the c++ application...
  applicationRun();

  /* USER CODE END 2 */

  /* Infinite loop */
}

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
/* MPU Configuration */

void MPU_Config(void)
{
  MPU_Region_InitTypeDef MPU_InitStruct = {0};

  /* Disables the MPU */
  HAL_MPU_Disable();

  /** Initializes and configures the Region and the memory to be protected
  */
  MPU_InitStruct.Enable = MPU_REGION_ENABLE;
  MPU_InitStruct.Number = MPU_REGION_NUMBER0;
  MPU_InitStruct.BaseAddress = 0x24000224;
  MPU_InitStruct.Size = MPU_REGION_SIZE_256B;
  MPU_InitStruct.SubRegionDisable = 0x0;
  MPU_InitStruct.TypeExtField = MPU_TEX_LEVEL0;
  MPU_InitStruct.AccessPermission = MPU_REGION_FULL_ACCESS;
  MPU_InitStruct.DisableExec = MPU_INSTRUCTION_ACCESS_DISABLE;
  MPU_InitStruct.IsShareable = MPU_ACCESS_NOT_SHAREABLE;
  MPU_InitStruct.IsCacheable = MPU_ACCESS_NOT_CACHEABLE;
  MPU_InitStruct.IsBufferable = MPU_ACCESS_NOT_BUFFERABLE;

  HAL_MPU_ConfigRegion(&MPU_InitStruct);
  /* Enables the MPU */
  HAL_MPU_Enable(MPU_PRIVILEGED_DEFAULT);

}

/**
  * @brief  This function is executed in case of error occurrence.
  * @retval None
  */
void Error_Handler(void)
{
  /* USER CODE BEGIN Error_Handler_Debug */
  /* User can add his own implementation to report the HAL error return state */
  debugWriteError("main", __LINE__, "error trapped");
  while (1)
  {
  }
  /* USER CODE END Error_Handler_Debug */
}

#ifdef  USE_FULL_ASSERT
/**
  * @brief  Reports the name of the source file and the source line number
  *         where the assert_param error has occurred.
  * @param  file: pointer to the source file name
  * @param  line: assert_param error line source number
  * @retval None
  */
void assert_failed(uint8_t *file, uint32_t line)
{
  /* USER CODE BEGIN 6 */
  /* User can add his own implementation to report the file name and line number,
     ex: printf("Wrong parameters value: file %s on line %d\r\n", file, line) */
  /* USER CODE END 6 */
}
#endif /* USE_FULL_ASSERT */

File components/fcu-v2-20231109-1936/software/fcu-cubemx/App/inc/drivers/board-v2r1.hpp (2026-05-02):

/*
 * board-v2r1.h
 *
 *  Created on: Oct 3, 2023
 *      Author: Daniel Johnson
 */
#ifndef BOARD_V2R1_H_
#define BOARD_V2R1_H_

#include <cstdio>
#include <cstdint>
#include <string>
#include <vector>
#include "stm32h7xx.h"
#include "stm32h7xx_hal.h"
#include "interrupts.h"
#include "component.hpp"
#include "board.hpp"
#include "mcu.hpp"
#include "indicator.hpp"
#include "stm32h723vgt6.hpp"
#include "debug.hpp"
#include "blinker.hpp"
#include "iic.hpp"
#include "uart.hpp"
#include "altitude-ranged.hpp"

#include "temperature.hpp"
#include "gyroscope.hpp"
#include "acceleration.hpp"
#include "magnetometer.hpp"
#include "heading-pitch-roll.hpp"
#include "acceleration-gravity.hpp"

#include "rcrx.hpp"
#include "rcrx-dsmx.hpp"
#include "rcrx-sbus.hpp"

#include "pwm.hpp"
#include "pwmdriver.hpp"
#include "pca9685pw.hpp"
#include "servo.hpp"

#include "a3g4250d.hpp"
#include "lis2hh12.hpp"
#include "asm330lhxxh.hpp"
#include "iis2mdc.hpp"
#include "ilps22qs.hpp"

#include "bno055.hpp"
#include "bme280.hpp"
#include "mb85rc256v.hpp"

#include "gps.hpp"
#include "uartgps.hpp"

#include "vtxclient.hpp"

extern const char* textError;
extern const char* textClassNameBoardV2R1;

#define BOARD_ATTITUDE_ROLL_OFFSET				(2.06250F)

class BoardV2R1 : public Board
{
private:
	Stm32h723vgt6* _stm32h723vgt6;
	Blinker*       _activityBlinker;
	Indicator*     _indicatorActivity;
	Indicator*     _indicatorWarning;
	Indicator*     _indicatorError;

	// i2c driver 4...
	A3g4250d*      						_a3g4250d		= NULL;
	Lis2hh12*      						_lis2hh12		= NULL;
	Asm330lhxxh*   						_asm330lhxxh	= NULL;
	Iis2mdc*       						_iis2mdc		= NULL;
	Ilps22qs*      						_ilps22qs		= NULL;

	// i2c driver 5...
	Pca9685pw*     						_pca9685pw   	= NULL;
	Servo*								_r_esc			= NULL;
	Servo*								_l_esc			= NULL;
	Servo*								_r_aileron		= NULL;
	Servo*								_l_aileron		= NULL;
	Servo*								_r_vtail		= NULL;
	Servo*								_l_vtail		= NULL;

	HasStatusAndSetup**					_externalComponents;
	uint8_t 							_externalComponentsCount;

	HasStatusAndSetup*					_componentsToSetup[20];
	uint8_t								_componentsToSetup_count = 0;
	HasStatusAndSetupAndCycle*			_componentsToCycle[20];
	uint8_t                             _componentsToCycle_count = 0;
	PwmDriver* 							_pwm = NULL;
	Gyroscope* 							_gyroscopes[8];
	uint8_t                             _gyroscopes_count = 0;
	Acceleration* 						_accelerometers[8];
	uint8_t                             _accelerometers_count = 0;
	LinearAcceleration*					_linearAccelerometers[8];
	uint8_t                             _linearAccelerometers_count = 0;
	Magnetometer*						_magnetometers[8];
	uint8_t                             _magnetometers_count = 0;
	BarometricPressure*					_barometers[8];
	uint8_t                             _barometers_count = 0;
	GravityAcceleration*				_gravitometers[8];
	uint8_t                             _gravitometers_count = 0;
	Temperature*						_thermometers[8];
	uint8_t                             _thermometers_count = 0;
	Humidity*							_hygrometers[8];
	uint8_t                             _hygrometers_count = 0;
	Gps*								_gpss[8];
	uint8_t                             _gpss_count = 0;
	Heading*							_compasses[8];
	uint8_t                             _compasses_count = 0;
	HeadingPitchRoll*					_imus[8];
	uint8_t                             _imus_count = 0;
	RangedAltitude*						_rangedaltitude[8];
	uint8_t								_rangedaltitude_count = 0;


	MovingAverage						maGyroscopeX;
	MovingAverage						maGyroscopeY;
	MovingAverage						maGyroscopeZ;
	uint8_t								_cycleStage = 0;

	RcRx* 								_rcrxA = NULL;
	RcRx* 								_rcrxB = NULL;
	RcRx* 								_rcrxC = NULL;
	Gps*								_gpsA  = NULL;
	uint8_t								_throttlePercentageR = 0;
	uint8_t								_throttlePercentageL = 0;
public:
	BoardV2R1(
		Stm32h723vgt6* mcu,
		Servo* r_esc,
		Servo* l_esc,
		Servo* r_aileron,
		Servo* l_aileron,
		Servo* r_vtail,
		Servo* l_vtail,
		HasStatusAndSetup** externalComponents,
		uint8_t externalComponentsCount
	)
	{
		_stm32h723vgt6           = mcu;
		_r_esc                   = r_esc;
		_l_esc                   = l_esc;
		_r_aileron               = r_aileron;
		_l_aileron               = l_aileron;
		_r_vtail                 = r_vtail;
		_l_vtail   				 = l_vtail;
		_externalComponents      = externalComponents;
		_externalComponentsCount = externalComponentsCount;
		_indicatorActivity       = new Indicator(GPIOC, GPIO_PIN_10);
		_indicatorWarning        = new Indicator(GPIOC, GPIO_PIN_11);
		_indicatorError          = new Indicator(GPIOC, GPIO_PIN_12);
		_activityBlinker         = new Blinker(_indicatorActivity, 5, 1000);
		_cycleStage              = 0;
	}
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

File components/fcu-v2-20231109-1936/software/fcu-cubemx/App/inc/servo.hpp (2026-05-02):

/*
 * servo.hpp
 *
 *  Created on: Oct 13, 2023
 *      Author: Daniel Johnson
 */
#ifndef APP_INC_SERVO_HPP_
#define APP_INC_SERVO_HPP_

#include <cstdint>
#include "pwmdriver.hpp"
#include "pwm.hpp"
#include "func.hpp"

class Servo
{
private:
	uint8_t    _channel       = 0;
	uint16_t   _hardLimitLow  = PWM_MINIMUM;
	uint16_t   _hardLimitHigh = PWM_MAXIMUM;
	uint16_t   _pwm           = PWM_CENTRE;
	float      _scaling       = 1.0;
	bool       _invert        = false;
public:
	Servo(const uint8_t outputChannel, const uint16_t initialPwm, const float scaling, const bool invert, const uint16_t hardLimitLow, const uint16_t hardLimitHigh)
	{
		_channel       = outputChannel;
		_hardLimitLow  = hardLimitLow;
		_hardLimitHigh = hardLimitHigh;
		_scaling       = scaling;
		_invert        = invert;
		pwm(initialPwm);
	}
	uint8_t channel() const
	{
		return _channel;
	}
	float scaling() const
	{
		return _scaling;
	}
	void scaling(const float value)
	{
		_scaling = value;
	}

	// pwm signal should always be normalised to 1000 to 2000...
	// hard limits are not scaled in any way
	// hard limits are to protect physical airframe and servos
	uint16_t pwm() const
	{
		return _pwm;
	}
	void pwm(const uint16_t pwm)
	{
		_pwm =
			bandpass<uint16_t>(
				unnormalise(
					(int16_t)multiply<float>(
						multiply<int16_t>(
							normalise(
								rescale<int16_t>(
									bandpass<int16_t>(pwm, PWM_MINIMUM, PWM_MAXIMUM),
									PWM_MINIMUM,
									PWM_MAXIMUM,
									_hardLimitLow,
									_hardLimitHigh
								)
							),
							-1,
							_invert
						),
						_scaling)
					),
				_hardLimitLow,
				_hardLimitHigh
			);
	}
};

#endif /* APP_INC_SERVO_HPP_ */

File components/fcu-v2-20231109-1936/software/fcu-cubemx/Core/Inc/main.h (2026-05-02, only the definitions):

#define SBUS_RX_Pin GPIO_PIN_2
#define SBUS_RX_GPIO_Port GPIOE
#define SBUS_TX_Pin GPIO_PIN_3
#define SBUS_TX_GPIO_Port GPIOE
#define SWDIO_Pin GPIO_PIN_13
#define SWDIO_GPIO_Port GPIOA
#define SWCLK_Pin GPIO_PIN_14
#define SWCLK_GPIO_Port GPIOA
#define LED_ACT_Pin GPIO_PIN_10
#define LED_ACT_GPIO_Port GPIOC
#define LED_WRN_Pin GPIO_PIN_11
#define LED_WRN_GPIO_Port GPIOC
#define LED_ERR_Pin GPIO_PIN_12
#define LED_ERR_GPIO_Port GPIOC

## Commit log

2026-04-12 Revise README for distributed flight control system
    Updated README to reflect distributed capabilities and added details on power management.
2026-04-12 Update README with Power Management details
    Added description for Power Management in README.
2026-04-12 Update power specifications in documentation
2026-04-12 Expand hardware specifications in documentation
    Added sections for Backbone Header, Minimum Stack Layers, Debug Connector, and detailed specifications for Power Distribution Board and Flight Control Board.
2026-04-12 Fix pin assignments and add CAN-FD connector section
2026-04-12 Revise MCU details and add debugging connector info
    Updated MCU specifications and added details for debugging connectors.
2026-04-16 Added kicad node template
    [hermetica-can-node-template.kicad_pcb, hermetica-can-node-template.kicad_sch, hermetica-current-monitoring.kicad_pcb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]
2026-04-16 reorganised file structure
    [3v3_reg.kicad_sch, aetherion-fcustack-maghead.kicad_pcb, aetherion-fcustack-maghead.kicad_sch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]
2026-04-27 Primarily added monitoring tool
    [hermetica-can-node-current-monitor.kicad_pcb, hermetica-can-node-current-monitor.kicad_sch, hermetica-can-node-esc-monitor.kicad_pcb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]
2026-04-27 Added monitoring tool
    [hermetica-esc-monitor-accelerometer.kicad_sch, hermetica-esc-monitor-high-current.kicad_pcb, hermetica-esc-monitor-high-current.kicad_sch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]
2026-04-29 updated pcbs
    [aetherion-fcustack-maghead.kicad_pcb, hermetica-debugging-interface.kicad_pcb, hermetica-debugging-interface.kicad_sch]
2026-05-02 FCU V2 REV1
    [3v3_reg.kicad_sch, backplane.kicad_sch, can.kicad_sch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]
2026-05-03 STM32H755ZIT6 dev board
    [analog.kicad_sch, can.kicad_sch, hermetica-fcustack-fcu.kicad_pcb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]

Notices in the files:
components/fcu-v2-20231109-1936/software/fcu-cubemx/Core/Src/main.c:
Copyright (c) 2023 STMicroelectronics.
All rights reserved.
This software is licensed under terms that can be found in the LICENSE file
